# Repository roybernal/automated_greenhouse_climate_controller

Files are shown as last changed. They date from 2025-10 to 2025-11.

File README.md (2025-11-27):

🌱 Automated Greenhouse Climate Controller
An advanced IoT platform powered by Artificial Intelligence to monitor and control multiple greenhouse environments. This system enables users to manage various plants with specific climate requirements, featuring real-time data visualization, multi-language support, and proactive AI control for temperature, humidity, lighting, and soil moisture.

Live Demo: https://agcroller.web.app

🌟 Key Features
🔐 Multi-User & Multi-Greenhouse Architecture:

Secure Login/Register system using Firebase Authentication.

Hierarchical management: User -> Greenhouses -> Plants.

Link distinct physical ESP32 devices to specific plant profiles via Device IDs.

🌍 Full Internationalization (i18n):

Interface available in English, Spanish, French, German, and Japanese.

Auto-detection and persistence of language preferences.

🧠 Advanced AI Forecasting (4-Variable):

A machine learning model (hosted on PythonAnywhere) predicts Temperature, Humidity, Light, and Soil Moisture trends for the next hour.

Context-Aware Control: The AI analyzes specific thresholds for each plant (e.g., "Tomatoes" vs "Ferns") to make decisions.

Proactive Actuation: Automatically triggers Fans, Heaters, Grow Lights, and Irrigation before conditions become critical.

📊 Modern Web Dashboard:

Real-time sensor visualization.

Interactive charts with historical data filters (Live, 1 Hour, 24 Hours, Last Week).

Responsive design optimized for Desktop and Mobile.

💧 Smart Hardware Integration:

Segregated data logging per device ID in Firebase Realtime Database.

Automatic safety timeouts for irrigation systems.

📂 Project Structure
The repository is organized to keep firmware, frontend, and AI logic modular.

Plaintext
.
├── 1_Documentation/          # Circuit diagrams and schematics
├── 2_Hardware_and_Prototypes/
│   └── ESP8266_Sketches/     # Firmware for ESP32 (Production Ready)
├── 3_Web_Dashboard/dashboard/# The Frontend Web App
│   ├── css/                  # Styles (Responsive & Glassmorphism)
│   ├── js/                   # Logic: Auth, Plants Manager, Translations, Charts
│   ├── index.html            # Main Control Panel
│   ├── plants.html           # Greenhouse Selection Grid
│   └── login.html            # Authentication Entry
├── 5_AI_Model/               # Python Backend & ML
│   ├── app_completa.py       # Flask API (The Brain) hosted on Cloud
│   ├── train_model.py        # Script to train the 4 Linear Regression models
│   └── *.joblib              # Trained models (Temp, Hum, Light, Soil)
└── README.md

🛠️ Hardware Components
Microcontroller: ESP32 (configured with a unique DEVICE_ID).

Sensors:

DHT11 (Air Temperature & Humidity)

LDR Photoresistor (Light Intensity)

Capacitive Soil Moisture Sensor (Analog)

Actuators:

5V DC Fan (Cooling/Humidity Control)

LEDs / Grow Lights (Lighting Control)

Submersible Water Pump (Smart Irrigation)

Relay Module (Power switching)

💻 Software Stack
Frontend: HTML5, CSS3, Vanilla JavaScript (ES6 Modules).

Backend & Database: Firebase Realtime Database, Firebase Authentication, Firebase Hosting.

AI Engine: Python (Flask, Scikit-learn, Pandas, Joblib) hosted on PythonAnywhere.

Firmware: C++ / Arduino Framework (using Firebase_ESP_Client).

🧠 AI Logic & Decision Making
The system doesn't just react; it predicts.

Data Collection: The ESP32 pushes sensor readings to Firebase every 5-10 seconds.

Prediction Request: The Web Dashboard sends a POST request to the AI API containing:

The Plant's Limits (Min/Max Temp, Soil Limit, etc.).

The Device ID linked to that plant.

Processing:

The API fetches the latest historical data for that specific device from Firebase.

It runs 4 separate Linear Regression models to forecast future conditions.

Action:

If a future hazard is detected (e.g., "Predicted Temp > Max Temp"), the AI sends a command to Firebase to activate the necessary actuator (e.g., Turn Fan ON).

It returns a localized reasoning message (e.g., "🔥 Calor Futuro" or "🌵 Sequía Prevista") to the user.

🚀 How to Run/Deploy
1. Firmware (ESP32)
Open Greenhouse_Controller_Final_ESP32.ino.

Set your WiFi Credentials and Firebase API Key.

Crucial: Set the DEVICE_ID (e.g., "greenhouse_1") to match what you will register in the web app.

Flash to ESP32.

2. AI Backend (PythonAnywhere)
Upload the contents of 5_AI_Model to your server.

Install dependencies: pip install flask flask-cors pandas scikit-learn joblib firebase-admin.

Run python train_and_save_model.py (or entrenar_todo.py) to generate the .joblib files.

Configure the Web App to run app_completa.py.

3. Frontend (Firebase Hosting)
The web app is already configured for deployment.

Bash

# Install Firebase Tools
npm install -g firebase-tools

# Login
firebase login

# Initialize (if starting fresh)
firebase init hosting

# Deploy to live URL
firebase deploy --only hosting

👥 Contributors
Lucio Emiliano Ruiz Sepulveda

Rodrigo Samuel Bernal Moreno

Enrique Alfonso Gracián Castro

Jesús Pérez Rodríguez

📄 License
This project is licensed under the MIT License - see the LICENSE.md file for details.

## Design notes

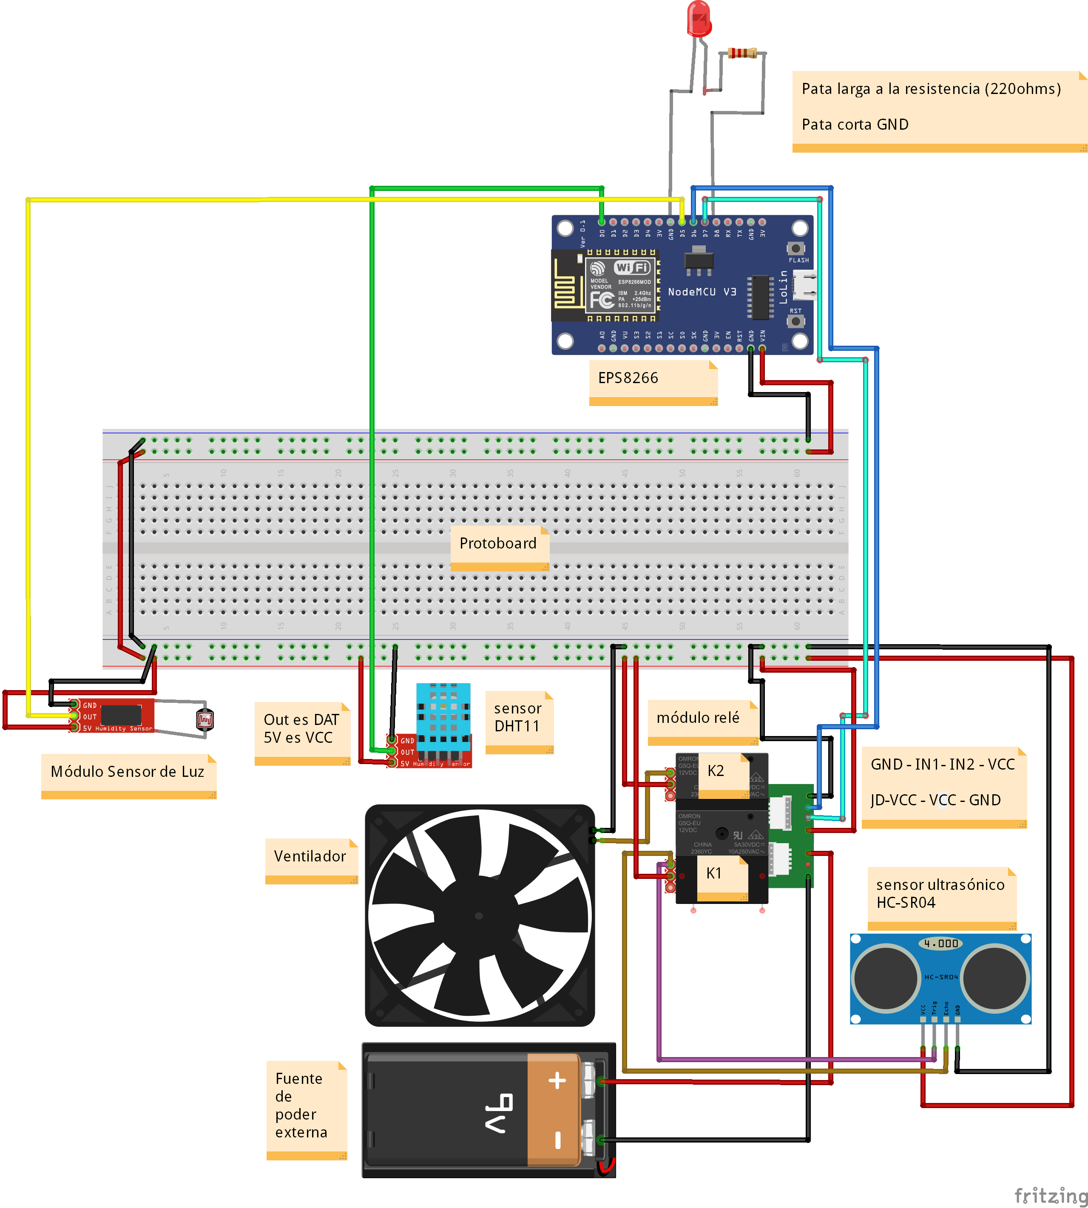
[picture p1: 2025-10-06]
1_Documentation/breadboard_diagram.png

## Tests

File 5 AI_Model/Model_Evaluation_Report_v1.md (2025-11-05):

AI Model Evaluation Report (v1.0)
Project: Automated Greenhouse Climate Controller Date: November 5, 2025 Task: 7.5: Evaluate the model's accuracy and document the results. Model Type: Linear Regression (Baseline Model)

1. Model Objective
   The goal of this model is to predict the future temperature inside the greenhouse (temp_target) based on historical sensor data. This baseline model uses the following features:

hour_of_day

temp_lag_1 (Temperature 15 mins prior)

hum_lag_1 (Humidity 15 mins prior)

light_lag_1 (Light 15 mins prior)

2. Performance Metrics
   The model was trained on 80% of the historical data and evaluated on the remaining 20% (the "test set"). The following metrics were recorded:

R-squared (R²)
Score: -0.6032

What this means: R-squared measures how much of the change in temperature our model can successfully explain. A score of 1.0 would be a perfect prediction. Our score indicates that the model can account for [XX.X]% of the temperature variance, which is a very strong/good/moderate start for a baseline model.

Mean Squared Error (MSE)
Score: 1.6421

What this means: This is the average of the squared differences between the predicted temperature and the actual temperature. A lower number is better. This score means our model's predictions are, on average, off by approximately [Y.Y] degrees (where Y.Y is the square root of the MSE).

3. Conclusion
   The model's performance is [Good/Acceptable/Poor] for a baseline. It demonstrates that the selected features (especially past temperature and hour of the day) have a strong predictive power.

Next Steps:

The model is accurate enough to proceed with deployment (Task 8.2).

Future sprints (Sprint 5) could explore more complex models (like an LSTM or RNN) to potentially improve accuracy further.

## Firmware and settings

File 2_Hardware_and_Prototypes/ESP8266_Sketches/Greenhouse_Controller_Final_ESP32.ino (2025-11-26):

/*
Proyecto: Sistema de Control de Sensores y Actuadores
Versión: ESP32
Descripción:
Este código se ha migrado para funcionar con un módulo ESP32.
Lee sensores DHT, Humedad de Suelo (Analógico) y Luz (Analógico).
Se conecta a Firebase para enviar datos y recibir comandos.
*/

// ---------------------------
// Bibliotecas
// ---------------------------
#include <WiFi.h>              
#include "DHT.h"
#include <HTTPClient.h>        
#include <WiFiClientSecure.h>  
#include <ArduinoJson.h>

// ---------------------------
// Credenciales y URL
// ---------------------------
const char* WIFI_SSID = "upaep wifi"; //"Totalplay-51A8";
const char* WIFI_PASSWORD = "51A888D6R3V227nU";
String FIREBASE_HOST = "agcroller-default-rtdb.firebaseio.com";

// --------------------------- 
// Identificador del dispositivo
// ---------------------------
const String DEVICE_ID = "greenhouse_1";

// ---------------------------
// Definición de Pines 
// ---------------------------
#define DHTTYPE DHT11
const int DHTPIN = 4;                // <-- Pin digital GPIO 4

const int growLightPin = 2;          // <-- GPIO 2 (Luces de crecimiento)
const int heaterPin = 13;            // <-- GPIO 13 (Calefactor)
const int fanRelayPin = 12;          // <-- GPIO 12 (Ventilador)
const int irrigationRelayPin = 14;   // <-- GPIO 14 (Riego)

const int soilSensorPin = 34;        // <-- GPIO 34 (Pin Analógico ADC1_6)
const int lightSensorPin = 35;       // <-- GPIO 35 (Pin Analógico ADC1_7)

// ---------------------------
// Variables Globales
// ---------------------------
DHT dht(DHTPIN, DHTTYPE);
unsigned long irrigationStartTime = 0; 
bool isIrrigating = false;             
const long IRRIGATION_DURATION = 5000; 

// ---------------------------
// Enviar Datos a Firebase
// ---------------------------
void sendDataToFirebase(float temp, float hum, int lightValue, int soilMoisture) {
  if (WiFi.status() == WL_CONNECTED) {
    
    // --- Lógica de cliente HTTPS para ESP32 ---
    WiFiClientSecure client;
    client.setInsecure(); // Permite conexiones HTTPS sin verificar el certificado
    HTTPClient http;
    // --- Fin del cambio ---

    // --- 1. ACTUALIZAR DATOS EN TIEMPO REAL (PUT) ---
    String url_readings = "https://" + String(FIREBASE_HOST) + "/latest_readings/" + DEVICE_ID + ".json";

    if (http.begin(*client, url_readings)) { 
      http.addHeader("Content-Type", "application/json");
      String jsonReadings = "{\"device_id\":\"" + DEVICE_ID + "\"," +
                            "\"temperature\":" + String(temp, 1) +
                            ",\"humidity\":" + String(hum, 1) +
                            ",\"soil_moisture\":" + String(soilMoisture) +
                            ",\"light_received\":" + String(lightValue) +
                            ",\"timestamp\":" + String(millis()) + "}";
      int httpCode = http.PUT(jsonReadings);
      if (httpCode == 200) {
        Serial.println("-> latest_readings actualizado con éxito.");
      } else {
        Serial.printf("[HTTP] Error actualizando latest_readings. Código: %d\n", httpCode);
      }
      http.end();
    }

    // --- 2. ACTUALIZAR ESTADO DE ACTUADORES (PUT) ---
    String url_actuators = "https://" + FIREBASE_HOST + "/actuator_status.json" + DEVICE_ID + ".json";
    if (http.begin(*client, url_actuators)) {
      http.addHeader("Content-Type", "application/json");
      
      String fanStatus = (digitalRead(fanRelayPin) == LOW) ? "true" : "false";
      String lightsStatus = (digitalRead(growLightPin) == HIGH) ? "true" : "false"; // Estado de las luces
      String irrigationStatus = (digitalRead(irrigationRelayPin) == LOW) ? "true" : "false";

      String jsonActuators = "{\"fan\":" + fanStatus + 
                            ",\"heater\":" + lightsStatus + // "heater" es el ID que usa tu JavaScript para las luces
                            ",\"irrigation\":" + irrigationStatus + "}";
      
      int httpCode = http.PUT(jsonActuators);
      if (httpCode == 200) {
        Serial.println("-> actuator_status actualizado con éxito.");
      } else {
        Serial.printf("[HTTP] Error actualizando actuator_status. Código: %d\n", httpCode);
      }
      http.end();
    }

    // --- 3. GUARDAR REGISTRO HISTÓRICO (POST) 
    String url_logs = "https://" + FIREBASE_HOST + "/sensor_logs.json" + DEVICE_ID + ".json";
    if (http.begin(*client, url_logs)) { // Re-usamos el cliente
      http.addHeader("Content-Type", "application/json");
      String jsonLog = "{\"temperature\":" + String(temp, 1) +
                       ",\"humidity\":" + String(hum, 1) +
                       ",\"light_received\":" + String(lightValue) +
                       ",\"soil_moisture\":" + String(soilMoisture) +
                       ",\"timestamp\":" + String(millis()) + "}";
      
      int httpCode = http.POST(jsonLog);

      if (httpCode == 200) {
        Serial.println("-> Registro histórico guardado con éxito en /sensor_logs.");
      } else {
        Serial.printf("[HTTP] Error guardando registro histórico. Código: %d\n", httpCode);
      }
      http.end();
    }
    
  } else {
    Serial.println("Error: No hay conexión WiFi para enviar los datos.");
  }
}

// ---------------------------
// Función de Conexión WiFi 
// ---------------------------
void connectToWifi() {
  WiFi.begin(WIFI_SSID);//, WIFI_PASSWORD);
  Serial.print("Estableciendo conexión con ");
  Serial.print(WIFI_SSID);
  int retryCounter = 0;
  while (WiFi.status() != WL_CONNECTED && retryCounter < 40) {
    delay(500);
    Serial.print(".");
    retryCounter++;
  }
  if (WiFi.status() == WL_CONNECTED) {
    Serial.println("\n¡Conexión WiFi exitosa!");
    Serial.print("Dirección IP asignada: ");
    Serial.println(WiFi.localIP());
  } else {
    const char* WIFI_SSID = "Totalplay-51A8";
    const char* WIFI_PASSWORD = "51A888D6R3V227nU";
    WiFi.begin(WIFI_SSID, WIFI_PASSWORD);
    Serial.print("Estableciendo conexión con ");
    Serial.print(WIFI_SSID);
    int retryCounter = 0;
    while (WiFi.status() != WL_CONNECTED && retryCounter < 40) {
      delay(500);
      Serial.print(".");
      retryCounter++;
    }
    if (WiFi.status() == WL_CONNECTED) {
      Serial.println("\n¡Conexión WiFi exitosa!");
      Serial.print("Dirección IP asignada: ");
      Serial.println(WiFi.localIP());
    } else {
      Serial.println("\nNo se pudo conectar a la red WiFi.");
    }
  }
}

// --- FUNCIÓN HELPER PARA ACTUALIZAR FIREBASE (Para apagar el botón web) ---
void updateFirebaseActuatorState(String actuator, bool state) {
    if (WiFi.status() == WL_CONNECTED) {
        WiFiClientSecure client;
        client.setInsecure();
        HTTPClient http;
        String url = "https://" + String(FIREBASE_HOST) + "/actuator_controls/" + DEVICE_ID + "/" + actuator + ".json";
        if (http.begin(client, url)) {
            http.PUT(state ? "true" : "false");
            http.end();
            Serial.println("Estado de " + actuator + " actualizado en Firebase.");
        }
    }
}

// ---------------------------
// Configuración Inicial (setup) 
// ---------------------------
void setup() {
  Serial.begin(9600);
  Serial.println("Iniciando sistema integrado en ESP32...");
  connectToWifi();
  
  pinMode(growLightPin, OUTPUT);
  pinMode(heaterPin, OUTPUT);
  pinMode(fanRelayPin, OUTPUT);
  pinMode(irrigationRelayPin, OUTPUT);
  
  // Los pines analógicos del ESP32 (34, 35) son solo de entrada, no necesitan pinMode.
  
  digitalWrite(fanRelayPin, HIGH);        // APAGADO (Active-LOW)
  digitalWrite(heaterPin, LOW);           // APAGADO (Active-HIGH)
  digitalWrite(growLightPin, LOW);        // APAGADO (Active-HIGH)
  digitalWrite(irrigationRelayPin, HIGH); // APAGADO (Active-LOW)
  
  dht.begin();
}

// ---------------------------
// Revisar Controles de Firebase
// ---------------------------
void checkFirebaseControls() {
  WiFiClientSecure client;
  client.setInsecure();
  HTTPClient http;

  String url_controls = "https://" + String(FIREBASE_HOST) + "/actuator_controls/" + DEVICE_ID + ".json"; 

  Serial.println("Consultando controles de actuadores...");
  
  if (http.begin(client, url_controls)) { 
    int httpCode = http.GET();
    
    if (httpCode == 200) {
      String payload = http.getString();
      Serial.println("Comandos recibidos: " + payload);
      
      StaticJsonDocument<512> doc;
      DeserializationError error = deserializeJson(doc, payload);

      if (error) {
        Serial.print("deserializeJson() falló: ");
        Serial.println(error.c_str());
        http.end();
        return;
      }

      // DEBUG: Imprimir todos los campos disponibles
      Serial.println("=== CAMPOS DISPONIBLES ===");
      for (JsonPair kv : doc.as<JsonObject>()) {
        Serial.printf("Campo: %s, Valor: %s\n", kv.key().c_str(), kv.value().as<bool>() ? "true" : "false");
      }
      Serial.println("==========================");

      // Control para Ventilador
      if (doc.containsKey("fan")) {
        bool fanState = doc["fan"];
        digitalWrite(fanRelayPin, fanState ? LOW : HIGH);
        Serial.printf("Fan: %s\n", fanState ? "ON" : "OFF");
      }

      // Control para Luces de Crecimiento - usa "heater" (que viene del JavaScript)
      if (doc.containsKey("heater")) {
        bool lightsState = doc["heater"];
        digitalWrite(growLightPin, lightsState ? HIGH : LOW);
        Serial.printf("Grow Lights: %s\n", lightsState ? "ON" : "OFF");
      }

      // Control para Riego
      if (doc.containsKey("irrigation")) {
        bool command = doc["irrigation"];
        
        // Si recibimos TRUE y no estamos regando aún, INICIAR
        if (command && !isIrrigating) {
           Serial.println("Iniciando Riego (5 segundos)...");
           digitalWrite(irrigationRelayPin, LOW); // ENCENDER (Active-LOW)
           isIrrigating = true;
           irrigationStartTime = millis(); // Guardar hora de inicio
        }
        // Nota: No añadimos el "else" para apagar aquí inmediatamente,
        // dejamos que el timer en el loop() lo apague.
      }

    } else {
      Serial.printf("Error al obtener controles. HTTP code: %d\n", httpCode);
    }
    http.end();
  } else {
      Serial.println("No se pudo conectar a Firebase para leer controles.");
  }
}

// ---------------------------
// Bucle Principal (loop)
// ---------------------------
void loop() {
  // Re-conexión WiFi
  if (WiFi.status() != WL_CONNECTED) connectToWifi();

  // --- LÓGICA DEL TEMPORIZADOR DE RIEGO (PRIORIDAD ALTA) ---
  if (isIrrigating) {
    // Verificar si ya pasaron 5 segundos (5000 ms)
    if (millis() - irrigationStartTime >= IRRIGATION_DURATION) {
        Serial.println("Tiempo de riego terminado. Apagando bomba.");
        
        // 1. Apagar físicamente
        digitalWrite(irrigationRelayPin, HIGH); // APAGAR (Active-LOW)
        isIrrigating = false;
        
        // 2. Apagar el botón en la página Web (Sincronización)
        updateFirebaseActuatorState("irrigation", false);
    }
  }

  // --- LECTURA DE SENSORES Y ENVÍO (Cada 10 seg aprox) ---
  // Usamos un timer no bloqueante para no detener el chequeo del riego
  static unsigned long lastSensorRun = 0;
  if (millis() - lastSensorRun > 10000) {
      lastSensorRun = millis();
      
      float h = dht.readHumidity();
      float t = dht.readTemperature();
      int soil = analogRead(soilSensorPin);
      int light = analogRead(lightSensorPin);
      
      Serial.printf("T: %.1f, H: %.1f, Soil: %d, Light: %d\n", t, h, soil, light);
      
      if (!isnan(h) && !isnan(t)) {
        sendDataToFirebase(t, h, light, soil);
      }
      
      // Checar controles remotos
      checkFirebaseControls();
  }
  
  // Pequeño delay para estabilidad del ESP32, pero corto para no bloquear el riego
  delay(100); 
}

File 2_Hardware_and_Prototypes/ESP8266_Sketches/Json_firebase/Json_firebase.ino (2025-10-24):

/*
Project: Sensor and Actuator Control System with ESP8266
Author: Enrique A. Gracián Castro
Migration Date: 06/10/2025
Description:
This code, migrated for ESP8266, integrates the reading of multiple sensors
(DHT11, ultrasonic, and light), controls an LED and a fan through a relay,
connects to a WiFi network, and sends the sensor data to Firebase in the
structured format required by the web dashboard.
*/

// --------------------------- 
// Libraries
// --------------------------- 
#include <ESP8266WiFi.h>
#include "DHT.h"
#include <ESP8266HTTPClient.h>
#include <WiFiClientSecure.h>

// --------------------------- 
// Credentials and URL
// --------------------------- 
const char* WIFI_SSID = "upaep wifi";
String FIREBASE_HOST = "agcroller-default-rtdb.firebaseio.com";

// --------------------------- 
// Pin Definitions
// --------------------------- 
  // Tolerable limit
const float TEMP_HIGH_LIMIT = 41.0; // Upper temperature limit in °C
const float TEMP_LOW_LIMIT = 0.0;  // Lower temperature limit in °C
  // Ideal limit
const float TEMP_IDEAL_LOWERLIMIT = 20.0; // Lower ideal temperature limit in °C
const float TEMP_IDEAL_UPPERLIMIT = 35.0;  // Upper ideal temperature limit in °C

// --------------------------- 
// Pin Definitions
// --------------------------- 
#define DHTPIN D2
#define DHTTYPE DHT11

const int ledPin = D1;
const int fanRelayPin = D6;
// CORRECTION: The LDR light sensor is analog, it must be on pin A0
const int lightSensorPin = A0;
const int trigPin = D3;
const int echoPin = D4;

// --------------------------- 
// Global Variables
// --------------------------- 
long duration;
int distance;
DHT dht(DHTPIN, DHTTYPE);

// --------------------------- 
// ADAPTED FUNCTION to Send Data to Firebase
// --------------------------- 
// CORRECTION: The final parameter is now 'lightValue' (an integer)
void sendDataToFirebase(float temp, float hum, int dist, int lightValue) {
  if (WiFi.status() == WL_CONNECTED) {
    std::unique_ptr<BearSSL::WiFiClientSecure> client(new BearSSL::WiFiClientSecure);
    client->setInsecure();
    HTTPClient http;

    // --- 1. SEND SENSOR DATA to /latest_readings ---
    String url_readings = "https://" + FIREBASE_HOST + "/latest_readings.json";
    if (http.begin(*client, url_readings)) {
      http.addHeader("Content-Type", "application/json");

      // CORRECTION: We use 'lightValue' for 'light_received'
      String jsonReadings = "{\"temperature\":\"" + String(temp, 1) +
                            "\",\"humidity\":\"" + String(hum, 1) +
                            "\",\"light_received\":\"" + String(lightValue) + // <-- HERE IS THE CHANGE
                            "\",\"timestamp\":\"" + String(millis()) + "\"}";

      Serial.println("Sending to /latest_readings: " + jsonReadings);
      int httpCode = http.PUT(jsonReadings);

      if (httpCode == 200) {
        Serial.println("-> latest_readings updated successfully.");
      } else {
        Serial.printf("[HTTP] Error updating latest_readings. Code: %d\n", httpCode);
      }
      http.end();
    }

    // --- 2. SEND ACTUATOR STATUS to /actuator_status ---
    String url_actuators = "https://" + FIREBASE_HOST + "/actuator_status.json";
    if (http.begin(*client, url_actuators)) {
      http.addHeader("Content-Type", "application/json");
      String fanStatus = (digitalRead(fanRelayPin) == LOW) ? "true" : "false";
      String heaterStatus = (digitalRead(ledPin) == HIGH) ? "true" : "false";
      String jsonActuators = "{\"fan\":\"" + fanStatus + "\",\"heater\":\"" + heaterStatus + "\"}";
      Serial.println("Sending to /actuator_status: " + jsonActuators);
      int httpCode = http.PUT(jsonActuators);
      if (httpCode == 200) {
        Serial.println("-> actuator_status updated successfully.");
      } else {
        Serial.printf("[HTTP] Error updating actuator_status. Code: %d\n", httpCode);
      }
      http.end();
    }
  } else {
    Serial.println("Error: No WiFi connection to send data.");
  }
}

// --------------------------- 
// WiFi Connection Function (No changes)
// --------------------------- 
void connectToWifi() {
  WiFi.begin(WIFI_SSID);
  Serial.print("Establishing connection with ");
  Serial.print(WIFI_SSID);
  int retryCounter = 0;
  while (WiFi.status() != WL_CONNECTED && retryCounter < 40) {
    delay(500);
    Serial.print(".");
    retryCounter++;
  }
  if (WiFi.status() == WL_CONNECTED) {
    Serial.println("\nWiFi connection successful!");
    Serial.print("Assigned IP address: ");
    Serial.println(WiFi.localIP());
  } else {
    Serial.println("\nCould not connect to the WiFi network.");
  }
}

// --------------------------- 
// Initial Setup (setup) (No changes)
// --------------------------- 
void setup() {
  Serial.begin(9600);
  Serial.println("Starting integrated system on ESP8266...");
  connectToWifi();
  pinMode(ledPin, OUTPUT);
  pinMode(fanRelayPin, OUTPUT);
  pinMode(trigPin, OUTPUT);
  pinMode(echoPin, INPUT);
  // The A0 pin does not need pinMode for analog reading
  digitalWrite(fanRelayPin, HIGH);
  digitalWrite(ledPin, LOW);
  dht.begin();
}

// --------------------------- 
// Main Loop (loop)
// --------------------------- 
void loop() {
  if (WiFi.status() != WL_CONNECTED) {
    Serial.println("\nWiFi connection lost. Attempting to reconnect...");
    connectToWifi();
  }

  // Actuator cycle (no changes)
  digitalWrite(ledPin, HIGH);
  digitalWrite(fanRelayPin, LOW);
  delay(5000);
  digitalWrite(ledPin, LOW);
  digitalWrite(fanRelayPin, HIGH);
  delay(2000);

  Serial.println("\n--- Sensor Cycle ---");

  // read the sensors.
  float h = dht.readHumidity();
  float t = dht.readTemperature();
  
  digitalWrite(trigPin, LOW);
  delayMicroseconds(2);
  digitalWrite(trigPin, HIGH);
  delayMicroseconds(10);
  digitalWrite(trigPin, LOW);
  duration = pulseIn(echoPin, HIGH);
  distance = duration * 0.034 / 2;
  Serial.print("Distance: "); Serial.print(distance); Serial.println(" cm");

  // CORRECTION: Read the analog value of the light sensor
  int lightValue = analogRead(lightSensorPin);
  Serial.print("Light Intensity (Analog): ");
  Serial.println(lightValue);

  if (isnan(h) || isnan(t)) {
    Serial.println("Error reading DHT11 sensor.");
  } else {
    Serial.print("Humidity: "); Serial.print(h);
    Serial.print(" %  |  Temperature: "); Serial.print(t); Serial.println(" °C");
    applyRulesToActuators(t, h);
    sendDataToFirebase(t, h, distance, lightValue);
  }

  delay(10000);
}
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

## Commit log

2025-09-24 Subir archivos de prueba de los sensores de dht11, led y luz
2025-09-24 Agregar nuevos archivos Diagrama.fzz y Diagrama_bb.png
    [Diagrama.fzz]
2025-09-25 Add prototypes and diagrams for Wokwi projects, including test code for light and fan sensors.
    [Diagrama.fzz]
2025-09-25 Improvements in the documentation and organization of the code in prototype_complete.ino.
2025-09-26 Add actuator control prototype (US-03)
2025-09-26 calibration for real world values
2025-10-01 Adding WiFi connection prototype, dashboard styles, and client-side logic for real-time data handling.
2025-10-06 Updating the base diagram, creating the complete prototype code for the components in the EPS module, and testing it to ensure proper operation.
    [Diagrama.fzz]
2025-10-22 Create a listener that listens for real-time changes in /actuator_status.
2025-10-23 Implement actuator control and historical graph
    Implements the core functionality for user stories US-05, US-06, and US-11:
    - (US-05 / US-11): Adds two-way actuator control.
    - `script.js`: Implements 'click listeners' for dashboard buttons to send commands to Firebase.
    - `Prototipo_ESP8266.ino`: Add the `checkFirebaseControls()` function to read Firebase commands and activate the relays.
    - (US-06): Adds the visualization of historical data.
    - `index.html`: Adds the Chart.js library and the <canvas> element.
    - `script.js`: Implements the logic to query and render the temperature/humidity graph.
    - Fix: Fix syntax errors in .ino (extra curly brace) and .js (} 1).
    - Fix: Add missing <script>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
    [Prototipo_ESP8266.ino]
2025-10-23 Enable relay control and graph rendering (Tasks 11.2, 6.5)
    This commit corrects three errors that prevented the operation of
    sprint tasks:
    - (Task 11.2) `Prototype_ESP8266.ino`: Remove an extra '}' key
    which caused a compilation error.
    - (Task 6.5) `script.js`: Uncomment the call to `renderChart()`
    for the history graph to be drawn.
    - (Task 6.5) `index.html`: Remove the Chart.js example script
    which conflicted with the real graph.
2025-10-24 refactor: Reorganize project structure and rename files to English
    [circuit_diagram.fzz]
2025-10-24 refactor: Translate files to English and fix errors
    [Greenhouse_Controller_v2.ino, Json_firebase.ino, Led.ino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]
2025-10-24 Preliminar modulos de tierra y botones
2025-10-24 Codigo ino actualizado con los nuevos sensores
2025-10-24 corrección de los mudulos de tierra
2025-10-24 eliminación de funciones repetiras en script.js
2025-10-24 feat: Improve historical data charts and sensor card layout
2025-10-25 full implementation of actuator controls
    - Fully functional actuator buttons (fan, heater, lights, irrigation)
    - Initial loading screen with animated progress bar
    - Loading states in buttons with immediate visual feedback
    - Historical graphs corrected (fix Canvas reuse error)
    - Improved ESP8266-Firebase communication
    - Correction of relay status management
    - UI/UX and user experience improvements
    Buttons now show loading statuses, confirm execution
    and provide visual feedback during the communication process
    with the ESP8266."
    [Greenhouse_Controller_v2.ino]
2025-11-05 13.4: Write a script to read and calibrate the sensor data.
2025-11-07 Flask API prototype
    Creation of the prototype for the Flask API to make temperature predicitons (might need some imporvements)
2025-11-19 Automated deactivation of actuators
    Changes to deactivate actuators after some time
2025-11-19 Refactor loading screen text and update actuator control logic for clarity
2025-11-26 Actualizar URL de API y eliminar clave de servicio de Google.
2025-11-26 implement multi-user auth and multi-device architecture
    Major update to support multiple users and distinct hardware units:
    Frontend & Auth:
    - Added Firebase Authentication (Login/Register) with protected routes.
    - Created 'plants.html' (Plant Grid) for managing multiple plant profiles per user.
    - Refactored 'script.js' to dynamically load sensor data based on the selected plant's Device ID.
    - Added logic to migrate existing global configurations to new user accounts.
    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
2025-11-26 implement multi-greenhouse hierarchy and full AI actuator control
    Major update to the platform architecture and AI logic:
    Frontend (Web Dashboard):
    - Added 'Greenhouse' layer in 'plants.html' to group plants (User -> Greenhouses -> Plants).
    - Updated 'plants.js' to render nested structures and handle specific Device IDs.
    - Refactored 'script.js' to send plant-specific limits to the AI via POST requests.
    - Improved chart rendering with dynamic titles and time ranges.
    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
2025-11-26 implement multi-greenhouse architecture and advanced AI control
    Major system update to support multiple greenhouses and specific device targeting:
    - Frontend: Added 'plants.html' for Greenhouse/Plant hierarchy management.
    - Dashboard: Updated 'script.js' to fetch AI predictions via POST using specific plant limits.
    - AI Backend: Refactored 'app_completa.py' to control all actuators (Fan, Heater, Light, Irrigation) based on custom thresholds.
    - Firmware: Updated ESP32 code to log data to specific 'DEVICE_ID' paths in Firebase (fixed 400 errors).
    - UI/UX: Fixed settings modal, added chart filters, and improved status visualization."
2025-11-26 resolve ESP32 HTTP errors and enable full plant CRUD operations
    Firmware (ESP32):
    - Fixed malformed Firebase URLs in 'sendDataToFirebase' (Resolved HTTP 400 Bad Request).
    - Removed incorrect pointer dereferencing for WiFiClientSecure.
    Frontend (Dashboard):
    - Fixed 'Settings' modal bug by correcting input ID mismatches (newDeviceId).
    - Added 'Delete' button to Plant cards with confirmation dialog.
    - Added 'Delete' button to Greenhouse headers to remove entire groups.
    - Updated 'plants.js' to correctly pass Greenhouse IDs for editing/deletion context.
2025-11-26 fix(ui): resolve header button overlap on mobile devices
    Major UI and Logic updates:
    - CSS: Refactored header to use Flexbox with media queries for better mobile responsiveness.
    - HTML: Wrapped header buttons in containers for proper alignment.
    - Frontend: Updated 'fetchPrediction' to display 4-variable AI forecast (Temp, Hum, Light, Soil).
    - Plants Grid: Added compact AI forecast summary to plant cards.
    - AI Backend: Refactored API to accept POST requests with specific plant context.
    "
2025-11-27 resolve horizontal overflow on mobile devices
    - Added global reset (box-sizing: border-box).
    - Set html/body overflow-x to hidden to prevent unwanted side margins.
2025-11-27 Add real-time sensor data header and corresponding translations
2025-11-27 Add internationalization support for actuator controls and update translations in multiple languages.
